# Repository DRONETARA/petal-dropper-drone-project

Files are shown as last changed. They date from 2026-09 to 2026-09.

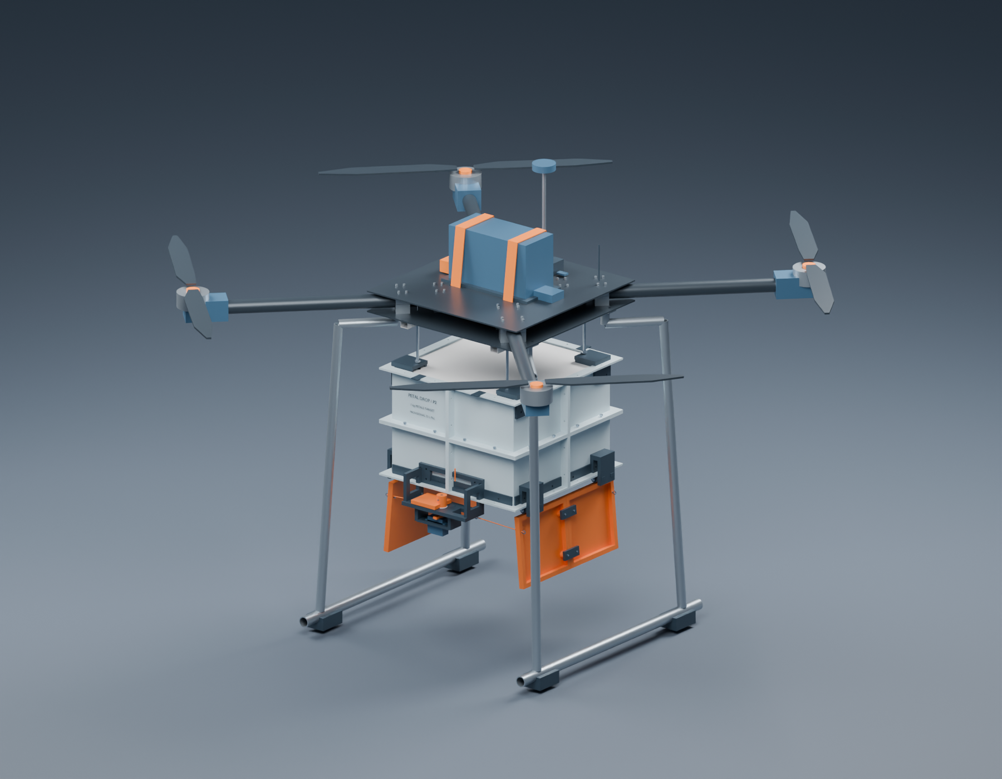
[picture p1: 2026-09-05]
deliverables/P2_selected_build_view_copy/Assembly_open.png

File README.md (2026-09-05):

# Petal Dropper Drone Project

This repository contains the complete Blender design package for Dronetara's flower-petal dropper drone. The current deliverable is P2: a selected-aircraft digital prototype with a 1 kg flower-petal target.

Start here:

- `deliverables/P2_selected_build/PetalDrop_1kg_Assembly.blend` is the editable P2 assembly in millimetres.
- `deliverables/P2_selected_build/STL_mm/` contains 46 individual printable attachment parts. Import at 100% in millimetres.
- `deliverables/P2_selected_build/README.md` is the build and assembly guide.
- `deliverables/P2_selected_build/Selected_components_BOM.csv`, `Electrical_and_Setup.md`, `Mass_and_Performance.md`, and `Fabrication/` contain the component selection, wiring approach, sizing, DXFs, and machining references.
- `deliverables/flap_opening_animation/PetalDrop_Flaps_Opening.mp4` is an 8.13-second close-up of the keeper release and flap opening. `PetalDrop_Flap_Opening_Review.blend` is the editable animation review scene; press Space in Blender to play it.

P2 selects a 1,300 mm Quad X with four Hobbywing X6 Plus G2 propulsion units, a Tattu 12S 22 Ah battery, Pixhawk 6X, PM08-CAN power module, M10 GPS, ELRS receiver, and two Hitec D954SW release servos. The package also retains the original starter assembly and P1 attachment prototype under `deliverables/`.

The design is a digital prototype, not a flight-ready aircraft. It targets 1 kg of petals, and its planning mass is about 20.3 kg including the target petals and contingency. Actual petal capacity, printed-part strength, release reliability, electronics, propulsion, landing structure, and flight performance are untested. The P2 qualification worksheet records the physical tests still required.

`packages/Dronetara_P2_Selected_Build.zip` is the standalone P2 handoff archive. `source/` retains the useful generation scripts, while P2's portable regeneration sources are also inside `deliverables/P2_selected_build/Source/`.

## Repository layout

| Path | Contents |
| --- | --- |
| `deliverables/Dronetara_Starter.blend` | Original editable starter drone |
| `deliverables/P1_attachment_prototype/` | Earlier P1 attachment, STL set, checks, and preview renders |
| `deliverables/P2_selected_build/` | Current selected-aircraft build package and 46-printable-part STL set |
| `deliverables/P2_selected_build_view_copy/` | Preserved alternate P2 Blender view copy; use the P2 build folder as canonical documentation |
| `deliverables/flap_opening_animation/` | Opening animation MP4, review Blender file, source frames, and verification notes |
| `packages/` | Portable P2 ZIP handoff |
| `source/` | Historical generation scripts used to create the project assets |

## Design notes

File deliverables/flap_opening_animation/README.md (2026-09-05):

# PetalDrop flap-opening animation

`PetalDrop_Flaps_Opening.mp4`: 8.13-second H.264 video, 800 x800, with a final open hold. Shows the existing keeper-release and two-door opening sequence. No flower particles or physics simulation are claimed.

`PetalDrop_Flap_Opening_Review.blend`: separate editable close-up presentation. Camera view, timeline1–105 at15fps; press Space in the viewport to play. The original P2 assembly and its full manual-reset timeline remain unchanged. Landing references are hidden in this review for visibility.

Verified poses: closed at1, keepers90°/doorsclosed at50, keepers90°/doors±95° at90.53 rendered source images, encoded at7.5 source frames/second into a30fps playback file. Full video decode succeeded and an extracted final frame was visually checked. Original P2 saved-file checksum is unchanged. Existing opening playback was also observed in the active Blender UI; the user's actively changing view was not replaced.

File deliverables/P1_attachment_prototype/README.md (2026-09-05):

# PetalDrop P1 — 1 kg petal-target bench prototype

**The target is at least 1 kg of flower petals alone.** The previous 200 g request is superseded. This package contains an editable drone-and-attachment assembly, 46 separate printable attachment parts, and an illustrated release/reset sequence. It is an untested mechanical prototype, not a demonstrated 1 kg-capable aircraft or a physically validated release system.

The original `Dronetara_Starter.blend` and its preview remain unchanged in the parent output folder. The new assembly uses the original visual drone enlarged **2.5 times in physical dimensions**, with an illustrative extended landing stand. That enlargement does not establish motor thrust, frame strength, endurance, or payload rating.

## Files and operation

- `PetalDrop_1kg_Assembly.blend`: editable assembly. One Blender unit represents one millimetre (`scale_length = 0.001`). Printable components are grouped in collections 10–14; purchased hardware and reference parts are separate.
- `STL_mm/`: 46 individual attachment components, one copy of each filename. STL has no intrinsic unit field: import as **millimetres, at 100% scale**. These files do not contain the decorative drone or landing stand.
- `parts_manifest.csv` / `.json`: each part's dimensions, quantity, nominal solid PETG mass and notes.
- `Assembly_closed.png`, `Assembly_open.png`: complete aircraft/reference-attachment views.
- `Mechanism_open.png`: better-lit underside detail; reference landing legs are hidden for this image only.
- `verification.json`: Blender topology, nominal wall/volume data and timeline collision sampling.
- `final_checks.json`: independent validation of the delivered STL binaries and a one-degree mechanism sweep, including reference landing legs.
- `limit_cords.json`: provisional door-stop cord lengths and assumptions.
- `hardware_BOM.csv`: purchased/fabricated hardware, separate from the print list.

Timeline markers describe the mechanism, rather than a physics simulation:

| Frames | State |
|---|---|
| 1 | Doors closed; keepers overlap the door ribs; removable transport pins installed |
| 20 | Both transport pins removed; operator has armed the mechanism |
| 20–50 | Two servos rotate the mechanical keepers through 90 degrees |
| 50–90 | Both doors swing down under gravity to the provisional 95-degree cord limit |
| 90–105 | Discharge opening exposed |
| 105–125 | **Manual** lifting of the empty doors, represented by keyframes |
| 125–155 | Servos return the keepers under the raised doors |
| 180 | Transport pins reinstalled |

This design intentionally uses gravity opening and manual reset. The servos do not lift 1 kg of petals or raise the doors. Support both empty doors by hand during reset, then close the keepers and insert the transport pins. Never command keeper closure into partly raised doors.

## Geometry and capacity assumptions

| Item | Provisional value |
|---|---:|
| Internal hopper plan | 320 × 320 mm |
| Interior bottom datum / top | Z354 / Z590 mm |
| Nominal gross enclosed volume | 24.166 L |
| Fill line | Z570 mm; 20 mm below the top |
| Geometric volume below fill line | 22.118 L, before displacement by hardware/cover |
| Minimum bulk density for 1 kg in that volume | 45.21 kg/m³; actual required density is slightly higher with displaced volume |
| Clear throat between support lips | 292 × 292 mm |
| Main hopper walls / bolt flanges | 2.4 / 4 mm |
| Door skins / ribs below skins | 2.4 / 9.6 mm |
| Module seam gap | 0.4 mm, sealed externally after assembly |
| Closed door skin to throat lip | 2 mm nominal vertical gap |
| Closed keeper to door rib | 0.5 mm nominal gap; doors settle onto keepers under load |
| Hinge pin / printed bore | 5.0 / 5.4 mm |
| Door knuckle to clevis | 2 mm nominal axial clearance at each end |
| Common M4 clearance holes | 4.4 mm |
| Provisional printer envelope | 220 × 220 × 220 mm |

The smooth interior and broad bottom opening reduce small-throat bridging risk, but wet petals, tangled petals and propwash can still prevent clean release. The cover is a **nonprinted fabric/net retention cover**, not a printed lid. Secure it around the rim and reinforce its four suspension-stud openings. The cover and fasteners displace some of the geometric volume.

### Measure the petals before claiming capacity

1. Weigh representative petals using the same variety, moisture and handling expected in use.
2. Fill a known-volume container loosely, without compressing the petals to make them fit. Repeat several times, including the loosest expected batch.
3. Compute bulk density as `mass_kg / volume_m³`, or required volume as `1 kg / measured density`.
4. Then test a full 1 kg batch in the assembled hopper below the fill line, with the cover installed. Record residual petals after release.

If the loosest batch needs more than the usable volume, this hopper does **not** meet the 1 kg requirement for that batch. Increase hopper volume or change the loading method and recheck the mechanism, mass, printer splits and clearances. No petal density was invented or measured during this design task.

## Mechanical load path and restraint

Petals rest on the ribbed doors. Door load is shared by the four steel-pin hinges and two wide keeper dogs. Each keeper overlaps the inner edges of **both** doors. Its axial load passes through a thrust washer into the printed carrier shelf, then through M4 fasteners into the hopper. The servo supplies rotation through a separate 6 mm spindle; its output bearing is not the intended vertical load support.

Hopper forces pass through the bolted corner shells to four suspension brackets, four M6 studs and two aluminium square-tube rails. Four rail clamps show a provisional connection to the visual airframe. Use through-bolts, washers and locking nuts rather than relying on printed threads.

Four adjustable, **nonprinted** 2 mm limit cords connect the keeper-carrier shelves to eye bolts on the door end ribs. Their geometry provides a nominal 95-degree opening stop. See `limit_cords.json` for eye-centre length; add the actual eye/loop/knot allowance and adjust on the physical assembly. Cord shape in Blender is illustrative. Verify routing, abrasion, shock load, knot security and angle before operating. The eye bolts and cord anchors are not strength-certified.

The small torsion-spring shapes are explicitly **hardware placeholders**. A spring, its end anchors and preload have not been selected or engineered. Do not rely on these shapes for automatic return or a power-loss fail-safe. The removable 3 mm transport pins are positive mechanical restraints when installed; remove both before servo actuation. Determine the required in-service power-loss behaviour before any aircraft integration.

## Mass, lift and actuator requirements

The mesh-volume estimate is approximately **3.73 kg for fully solid PETG**, using an assumed density of 1.27 g/cm³. This is not a slicer result or weighed mass. Infill may reduce some thick-part mass, while supports, hardware and finishing change the actual totals. Thin walls cannot be treated as empty infill volumes.

| Load item | Current status |
|---|---|
| Petals | Required target: **at least 1.000 kg** |
| Printed attachment | Approximately 3.73 kg if solid PETG; see manifest for exact current estimate |
| Rails, studs, fasteners, actuators, cover, cords, wiring | Provisional planning allowance **1.0–1.4 kg**; choose and weigh actual hardware |
| Added load carried by aircraft | Approximately **5.7–6.1 kg** under the solid-print assumption, excluding any new landing gear |
| Actual drone empty mass, lift margin and endurance | Unknown |

The attachment is therefore a substantial bench prototype, not a demonstrated lightweight flight payload. Slicer estimates and a weighed build are required before matching it to an airframe. The visual drone's propellers, motors and enlarged geometry supply no evidence of lift capacity.

For an **illustrative, unvalidated 3 g load case**, 5.7–6.1 kg creates about 168–180 N total vertical force, or 42–45 N per suspension point if perfectly shared. Real loads need not share evenly. This calculation is a sizing input only: no material coupon testing, stress analysis, fatigue assessment, pull-out test or structural proof test was performed.

Each servo model is a placeholder, not a verified purchasable actuator. The current interface assumes:

- Body envelope: 40.5 × 20.5 × 40 mm, with shaft axis offset 10 mm from body centre.
- Ear-hole pattern: 49.5 × 10 mm, using 3.4 mm printed clearance holes.
- Purchased horn: four M2.5 attachment screws on a **provisional 17 mm pitch circle**.
- Separate 6 mm steel spindle with two M3 cross-bolt connections. Confirm actual shaft machining, fit, fastener strength and access.
- At least 90 degrees of usable commanded travel, with calibrated closed/open limits.

A conservative starting selection calculation is `T ≈ friction coefficient × supported force × contact radius`. Assuming 0.4 friction, about 1.7 kg of doors plus petals temporarily loading one keeper, and a 60 mm effective radius gives roughly **0.4 N·m**. A factor of three gives **1.2 N·m of verified usable torque**, before spring, dirt or jam allowances. This is not a stall-torque endorsement or a measured requirement. Select the actuator using its real voltage, duty and torque data, then rework the provisional horn adapter and carrier if needed.

Power the actuators from a correctly rated supply/BEC; establish stall/current demand and signal compatibility from the selected hardware. Do not assume an autopilot's signal header can power two high-torque servos. No autopilot wiring, software or failsafe configuration is supplied because the controller is unknown.

## Printing and assembly

All 46 files fit within the provisional 220 mm cube. Each STL is translated to the build plane and oriented along a bounding-box axis; this is a packaging orientation, **not a guarantee of support-free printing or optimal layer strength**. Confirm orientation in the slicer.

Suggested starting process: calibrated 0.4 mm nozzle and 0.2 mm layers. The 2.4 mm skins are nominally six 0.4 mm extrusion widths, but actual slicer line width matters. Print a hinge/clearance sample before the full set. Use a suitable tested material profile and orient structural brackets so primary loads do not simply peel apart layer interfaces. No generic infill percentage establishes strength.

1. Assemble the eight hopper corner modules with M4 screws, wide washers and locknuts. Keep the 0.4 mm seam gaps consistent and seal them externally. Do not rely on adhesive alone.
2. Add the eight throat rails, four hinge clevises and four upper suspension brackets using their matching through-holes.
3. Join each two-tile door using its two underside splice plates. Fit steel hinge pins, thrust washers and positive pin retention. Check free rotation with the servos/cords disconnected.
4. Assemble each keeper carrier, thrust washer, spindle, keeper and **hardware-matched** horn adapter. Install the selected actuator and verify its mounting and output axis before tightening.
5. Fit the four M4 limit-cord eye anchors on carriers and four on doors. Adjust the four cords evenly while physically supporting the open doors. Check that slack cords stay clear of latches, shafts and the release opening.
6. Fit the M6 suspension studs, rails and removable rail clamps. The airframe interface must be adapted to the actual frame, not drilled from the decorative model by assumption.
7. Secure the fabric cover, wiring and any tethering so nothing can enter the propellers or catch a door.

Fastener lengths in the BOM are provisional. Measure the assembled stack, allow full nut engagement, retain moving pins, and check that projecting threads do not obstruct petals or moving parts.

## Verification and physical tests still required

The final reports distinguish Blender topology checks from independent **STL-binary** checks. Tiny boolean slivers were cleaned at 0.001 mm tolerance, and mirrored normals were corrected. Confirm the latest `final_checks.json`: all delivered files should have zero boundary/nonmanifold edges, zero degenerate triangles and positive signed volume.

The mechanism was also swept at one-degree increments through keeper release and door opening, checking printed parts against fixed print geometry and the illustrative landing legs. This is sampled surface-intersection checking, not a continuous collision proof or a deformation/contact simulation. Metal pins, washers, springs, servo internals, wiring, cables under load and real petals require physical checks. Nominal wall/skin dimensions are design inputs, not a complete minimum-wall scan of every bolt ligament.

Before evaluating a flight installation:

- **Dimensional fit:** gauge every pin, eye, bolt, actuator and rail fit; check washer/nut access and full travel by hand.
- **Loaded retention:** support the assembly in a bench fixture with propellers removed. Load an actual 1 kg batch, hold it closed, inspect deflection and verify that both keepers and all pins remain secure. Establish proof loads with an engineer from the intended acceleration and material data.
- **Release reliability:** measure commanded-to-release time, current peaks, servo temperature, residual mass and any asymmetric opening. Repeat with dry and damp petals, partial/full fills and expected gentle motion. A useful initial screening is 20 successful bench releases; it is not a reliability qualification.
- **Reset/transport:** test manual reset, the two removable pins and cord routing after every cycle. Define and test loss-of-power behaviour.
- **Actual aircraft:** obtain frame mounting dimensions, permitted takeoff mass, motor/propeller/battery data, thrust margin, payload CG limits, controller/servo interface and real ground clearance. Include the entire attachment, hardware and modified landing gear in the load budget.

### Design references

Printing orientation and fit allowances must be adapted to the process; see [Prusa: Modeling with 3D printing in mind](https://help.prusa3d.com/article/modeling-with-3d-printing-in-mind_164135).

Servo supply sizing must account for current demand rather than signal compatibility alone; see [Pololu: Electrical characteristics of servos](https://www.pololu.com/blog/16/electrical-characteristics-of-servos-and-introduction-to-the-servo-control-interface).

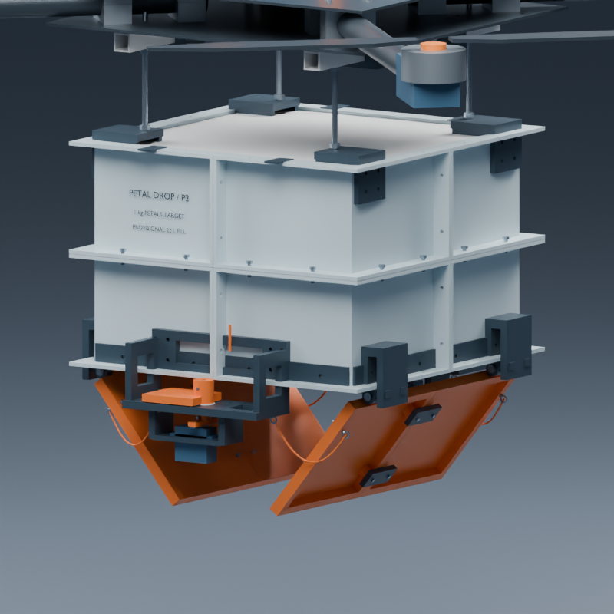
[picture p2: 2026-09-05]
deliverables/flap_opening_animation/frames/frame_0071.png

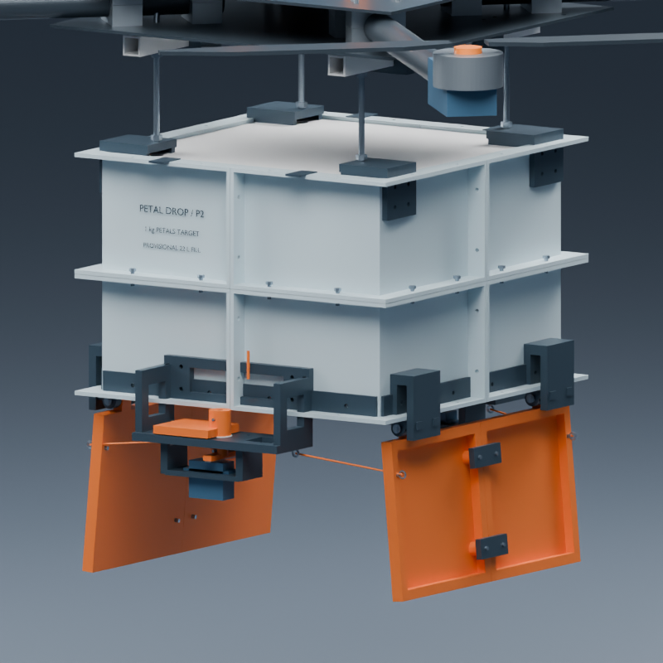
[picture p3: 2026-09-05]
deliverables/flap_opening_animation/frames/frame_0093.png

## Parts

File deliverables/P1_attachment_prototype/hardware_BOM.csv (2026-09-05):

Item | Quantity | Provisional size or interface | Notes
Hopper module joining bolts | 32 | M4 x 16 with washers and locknuts | 16 vertical seam and 16 horizontal seam bolts
Throat rail bolts | 16 | M4 x 14 with washers and locknuts | Check stacked wall and rail thickness
Hinge clevis mounting bolts | 16 | M4 x 20 with washers and locknuts | Verify engagement and no projecting petal snags
Keeper carrier mounting bolts | 16 | M4 x 20 with washers and locknuts | Four bolt holes on each half of each carrier
Suspension bracket bolts | 16 | M4 x 18 with wide washers and locknuts | Load path into thin hopper wall requires testing
Door splice bolts | 8 | M4 x 22 with washers and locknuts | Two bolts per splice plate
Rail clamp bolts | 16 | M4 x 40 with washers and locknuts | Four bolts per split clamp; actual frame interface unknown
Door-limit eye bolts | 8 | M4 with washers and locknuts | Four carrier anchors and four door anchors; select stem length from actual stack
Door-limit cords | 4 | 2 mm nominal adjustable cord | Provisional 100 N WLL target each; eye-centre lengths in limit_cords.json; verify knots and shock load
Hinge pins | 4 | 5 mm stainless steel x 48 mm | Add washers and positive end retention; not printed pins
Hinge thrust washers | 8 | 5 mm ID | Allow for actual washer thickness when fitting
Keeper spindles | 2 | 6 mm steel x 44 mm | Two M3 cross connections; machining and strength need review
Spindle cross bolts | 4 | M3 x 26 with locking nuts | Match shaft and adapter hole alignment
Keeper thrust washers | 2 | 6.6 mm ID x 24 mm OD x 1 mm | Payload axial force bears on carrier shelf
Transport arming pins | 2 | 3 mm x 28 mm with retention loop | Remove both before commanded release
Servos | 2 | UNSELECTED; provisional 40.5 x 20.5 x 40 mm | Verify usable torque not stall rating; voltage duty current horn and hole pattern
Servo mounting screws | 8 | M3 with washers and locking nuts | Provisional 49.5 x 10 mm mounting pattern
Purchased servo horns | 2 | UNSELECTED; provisional 17 mm four-hole PCD | Printed adapter is not a verified servo spline
Horn adapter screws | 8 | M2.5 | Actual horn determines length and pattern
Return springs | 2 | UNSELECTED; shown schematically only | End anchors and preload not engineered; not a verified failsafe
Suspension studs | 4 | M6 x 136 mm | Use actual frame dimensions before cutting
Suspension nuts | 12 | M6 locking nuts plus wide washers | Verify clearance and secure engagement
Mount rails | 2 | Aluminium square tube 20 x 20 x 2 mm x 350 mm | Drill M6 stud holes at +/-130 mm; actual frame interface unknown
Retention cover | 1 | Light fabric or suitable net about 320 x 320 mm | Reinforce four stud cutouts and secure all edges; validate propwash
Cover straps | 4 | Nonprinted straps | Keep away from propellers
Power supply and wiring | 1 | UNSELECTED BEC wiring connector set | Size for selected actuators and actual controller interface
Illustrative landing stand | 0 | Not included in printable attachment BOM | New landing gear must be engineered and counted in actual aircraft mass

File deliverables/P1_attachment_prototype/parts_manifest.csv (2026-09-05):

part | STL file | quantity | X mm | Y mm | Z mm | solid PETG grams | nonmanifold edges | components | print notes
Hopper_lower_-1_-1 | Hopper_lower_m1_m1.stl | 1 | 181.8 | 181.8 | 119.8 | 206.9 | 0 | 1 | 2.4 mm walls; 4 mm outside bolt flanges; 0.4 mm module gaps. M4 through-bolts, washers, locknuts. Seal joints externally with tape. Print with flange supports. Mesh merged at 0.001 mm tolerance; outward STL normals verified. Mesh merged at 0.001 mm tolerance; outward STL normals verified.
Hopper_lower_-1_+1 | Hopper_lower_m1_p1.stl | 1 | 181.8 | 181.8 | 119.8 | 206.9 | 0 | 1 | 2.4 mm walls; 4 mm outside bolt flanges; 0.4 mm module gaps. M4 through-bolts, washers, locknuts. Seal joints externally with tape. Print with flange supports. Mesh merged at 0.001 mm tolerance; outward STL normals verified. Mesh merged at 0.001 mm tolerance; outward STL normals verified.
Hopper_lower_+1_-1 | Hopper_lower_p1_m1.stl | 1 | 181.8 | 181.8 | 119.8 | 206.9 | 0 | 1 | 2.4 mm walls; 4 mm outside bolt flanges; 0.4 mm module gaps. M4 through-bolts, washers, locknuts. Seal joints externally with tape. Print with flange supports. Mesh merged at 0.001 mm tolerance; outward STL normals verified. Mesh merged at 0.001 mm tolerance; outward STL normals verified.
Hopper_lower_+1_+1 | Hopper_lower_p1_p1.stl | 1 | 181.8 | 181.8 | 119.8 | 206.9 | 0 | 1 | 2.4 mm walls; 4 mm outside bolt flanges; 0.4 mm module gaps. M4 through-bolts, washers, locknuts. Seal joints externally with tape. Print with flange supports. Mesh merged at 0.001 mm tolerance; outward STL normals verified. Mesh merged at 0.001 mm tolerance; outward STL normals verified.
Hopper_upper_-1_-1 | Hopper_upper_m1_m1.stl | 1 | 181.8 | 181.8 | 119.8 | 207.2 | 0 | 1 | 2.4 mm walls; 4 mm outside bolt flanges; 0.4 mm module gaps. M4 through-bolts, washers, locknuts. Seal joints externally with tape. Print with flange supports. Mesh merged at 0.001 mm tolerance; outward STL normals verified. Mesh merged at 0.001 mm tolerance; outward STL normals verified.
Hopper_upper_-1_+1 | Hopper_upper_m1_p1.stl | 1 | 181.8 | 181.8 | 119.8 | 207.2 | 0 | 1 | 2.4 mm walls; 4 mm outside bolt flanges; 0.4 mm module gaps. M4 through-bolts, washers, locknuts. Seal joints externally with tape. Print with flange supports. Mesh merged at 0.001 mm tolerance; outward STL normals verified. Mesh merged at 0.001 mm tolerance; outward STL normals verified.
Hopper_upper_+1_-1 | Hopper_upper_p1_m1.stl | 1 | 181.8 | 181.8 | 119.8 | 207.2 | 0 | 1 | 2.4 mm walls; 4 mm outside bolt flanges; 0.4 mm module gaps. M4 through-bolts, washers, locknuts. Seal joints externally with tape. Print with flange supports. Mesh merged at 0.001 mm tolerance; outward STL normals verified. Mesh merged at 0.001 mm tolerance; outward STL normals verified.
Hopper_upper_+1_+1 | Hopper_upper_p1_p1.stl | 1 | 181.8 | 181.8 | 119.8 | 207.2 | 0 | 1 | 2.4 mm walls; 4 mm outside bolt flanges; 0.4 mm module gaps. M4 through-bolts, washers, locknuts. Seal joints externally with tape. Print with flange supports. Mesh merged at 0.001 mm tolerance; outward STL normals verified. Mesh merged at 0.001 mm tolerance; outward STL normals verified.
Throat_rail_X_-1_-1 | Throat_rail_X_m1_m1.stl | 1 | 159.6 | 24.0 | 19.4 | 27.8 | 0 | 1 | Inward 12 mm support lip; 2 mm vertical clearance over shut doors. M4 attachment. Clear aperture 292 x 292 mm. Mesh merged at 0.001 mm tolerance; outward STL normals verified. Mesh merged at 0.001 mm tolerance; outward STL normals verified.
Throat_rail_X_-1_+1 | Throat_rail_X_m1_p1.stl | 1 | 159.6 | 24.0 | 19.4 | 27.8 | 0 | 1 | Inward 12 mm support lip; 2 mm vertical clearance over shut doors. M4 attachment. Clear aperture 292 x 292 mm. Mesh merged at 0.001 mm tolerance; outward STL normals verified. Mesh merged at 0.001 mm tolerance; outward STL normals verified.
Throat_rail_X_+1_-1 | Throat_rail_X_p1_m1.stl | 1 | 159.6 | 24.0 | 19.4 | 27.8 | 0 | 1 | Inward 12 mm support lip; 2 mm vertical clearance over shut doors. M4 attachment. Clear aperture 292 x 292 mm. Mesh merged at 0.001 mm tolerance; outward STL normals verified. Mesh merged at 0.001 mm tolerance; outward STL normals verified.
Throat_rail_X_+1_+1 | Throat_rail_X_p1_p1.stl | 1 | 159.6 | 24.0 | 19.4 | 27.8 | 0 | 1 | Inward 12 mm support lip; 2 mm vertical clearance over shut doors. M4 attachment. Clear aperture 292 x 292 mm. Mesh merged at 0.001 mm tolerance; outward STL normals verified. Mesh merged at 0.001 mm tolerance; outward STL normals verified.
Throat_rail_Y_-1_-1 | Throat_rail_Y_m1_m1.stl | 1 | 24.0 | 159.6 | 19.4 | 26.6 | 0 | 1 | Inward 12 mm support lip; 2 mm vertical clearance over shut doors. M4 attachment. Clear aperture 292 x 292 mm. Mesh merged at 0.001 mm tolerance; outward STL normals verified. Mesh merged at 0.001 mm tolerance; outward STL normals verified.
Throat_rail_Y_-1_+1 | Throat_rail_Y_m1_p1.stl | 1 | 24.0 | 159.6 | 19.4 | 26.6 | 0 | 1 | Inward 12 mm support lip; 2 mm vertical clearance over shut doors. M4 attachment. Clear aperture 292 x 292 mm. Mesh merged at 0.001 mm tolerance; outward STL normals verified. Mesh merged at 0.001 mm tolerance; outward STL normals verified.
Throat_rail_Y_+1_-1 | Throat_rail_Y_p1_m1.stl | 1 | 24.0 | 159.6 | 19.4 | 26.6 | 0 | 1 | Inward 12 mm support lip; 2 mm vertical clearance over shut doors. M4 attachment. Clear aperture 292 x 292 mm. Mesh merged at 0.001 mm tolerance; outward STL normals verified. Mesh merged at 0.001 mm tolerance; outward STL normals verified.
Throat_rail_Y_+1_+1 | Throat_rail_Y_p1_p1.stl | 1 | 24.0 | 159.6 | 19.4 | 26.6 | 0 | 1 | Inward 12 mm support lip; 2 mm vertical clearance over shut doors. M4 attachment. Clear aperture 292 x 292 mm. Mesh merged at 0.001 mm tolerance; outward STL normals verified. Mesh merged at 0.001 mm tolerance; outward STL normals verified.
Door_tile_-1_-1 | Door_tile_m1_m1.stl | 1 | 176.5 | 159.3 | 16.0 | 156.0 | 0 | 1 | 2.4 mm skin; 9.6 mm ribs; 5.4 mm pin bore. Print flat with ribs upward. M4 splice plates underneath. Mesh merged at 0.001 mm tolerance; outward STL normals verified. Mesh merged at 0.001 mm tolerance; outward STL normals verified.
Hinge_clevis_-1_-1 | Hinge_clevis_m1_m1.stl | 1 | 48.0 | 64.0 | 30.0 | 63.2 | 0 | 1 | M4 bolts to hopper wall; 5 mm stainless pin, washers and split pins. 2 mm axial running clearance per side. Mesh merged at 0.001 mm tolerance; outward STL normals verified. Mesh merged at 0.001 mm tolerance; outward STL normals verified.
Door_tile_-1_+1 | Door_tile_m1_p1.stl | 1 | 176.5 | 159.3 | 16.0 | 156.0 | 0 | 1 | 2.4 mm skin; 9.6 mm ribs; 5.4 mm pin bore. Print flat with ribs upward. M4 splice plates underneath. Mesh merged at 0.001 mm tolerance; outward STL normals verified. Mesh merged at 0.001 mm tolerance; outward STL normals verified.
Hinge_clevis_-1_+1 | Hinge_clevis_m1_p1.stl | 1 | 48.0 | 64.0 | 30.0 | 63.2 | 0 | 1 | M4 bolts to hopper wall; 5 mm stainless pin, washers and split pins. 2 mm axial running clearance per side. Mesh merged at 0.001 mm tolerance; outward STL normals verified. Mesh merged at 0.001 mm tolerance; outward STL normals verified.
Door_splice_-1_35 | Door_splice_m1_35.stl | 1 | 20.0 | 48.0 | 6.0 | 7.1 | 0 | 1 | M4 x 22 through-bolts; underside of tile joint. Mesh merged at 0.001 mm tolerance; outward STL normals verified. Mesh merged at 0.001 mm tolerance; outward STL normals verified.
Door_splice_-1_125 | Door_splice_m1_125.stl | 1 | 20.0 | 48.0 | 6.0 | 7.1 | 0 | 1 | M4 x 22 through-bolts; underside of tile joint. Mesh merged at 0.001 mm tolerance; outward STL normals verified. Mesh merged at 0.001 mm tolerance; outward STL normals verified.
Door_tile_+1_-1 | Door_tile_p1_m1.stl | 1 | 176.5 | 159.3 | 16.0 | 156.0 | 0 | 1 | 2.4 mm skin; 9.6 mm ribs; 5.4 mm pin bore. Print flat with ribs upward. M4 splice plates underneath. Mesh merged at 0.001 mm tolerance; outward STL normals verified. Mesh merged at 0.001 mm tolerance; outward STL normals verified.
Hinge_clevis_+1_-1 | Hinge_clevis_p1_m1.stl | 1 | 48.0 | 64.0 | 30.0 | 63.2 | 0 | 1 | M4 bolts to hopper wall; 5 mm stainless pin, washers and split pins. 2 mm axial running clearance per side. Mesh merged at 0.001 mm tolerance; outward STL normals verified. Mesh merged at 0.001 mm tolerance; outward STL normals verified.
Door_tile_+1_+1 | Door_tile_p1_p1.stl | 1 | 176.5 | 159.3 | 16.0 | 156.0 | 0 | 1 | 2.4 mm skin; 9.6 mm ribs; 5.4 mm pin bore. Print flat with ribs upward. M4 splice plates underneath. Mesh merged at 0.001 mm tolerance; outward STL normals verified. Mesh merged at 0.001 mm tolerance; outward STL normals verified.
Hinge_clevis_+1_+1 | Hinge_clevis_p1_p1.stl | 1 | 48.0 | 64.0 | 30.0 | 63.2 | 0 | 1 | M4 bolts to hopper wall; 5 mm stainless pin, washers and split pins. 2 mm axial running clearance per side. Mesh merged at 0.001 mm tolerance; outward STL normals verified. Mesh merged at 0.001 mm tolerance; outward STL normals verified.
Door_splice_+1_35 | Door_splice_p1_35.stl | 1 | 20.0 | 48.0 | 6.0 | 7.1 | 0 | 1 | M4 x 22 through-bolts; underside of tile joint. Mesh merged at 0.001 mm tolerance; outward STL normals verified. Mesh merged at 0.001 mm tolerance; outward STL normals verified.
Door_splice_+1_125 | Door_splice_p1_125.stl | 1 | 20.0 | 48.0 | 6.0 | 7.1 | 0 | 1 | M4 x 22 through-bolts; underside of tile joint. Mesh merged at 0.001 mm tolerance; outward STL normals verified. Mesh merged at 0.001 mm tolerance; outward STL normals verified.
Keeper_dog_-1 | Keeper_dog_m1.stl | 1 | 56.0 | 71.0 | 25.0 | 44.3 | 0 | 1 | Positive overlap under BOTH leaves; 90 degree release. 6 mm spindle; M3 cross-bolt. Removable 3 mm arming pin. Servo must return closed before manual reset. Mesh merged at 0.001 mm tolerance; outward STL normals verified. Mesh merged at 0.001 mm tolerance; outward STL normals verified.
Servo_keeper_carrier_-1 | Servo_keeper_carrier_m1.stl | 1 | 97.0 | 170.0 | 65.6 | 207.0 | 0 | 1 | Shelf carries axial petal load via washer, not servo output bearing. Actuator envelope/49.5 x 10 hole pattern provisional; verify against purchased hardware. Mesh merged at 0.001 mm tolerance; outward STL normals verified. Mesh merged at 0.001 mm tolerance; outward STL normals verified.
Horn_adapter_PROVISIONAL_-1 | Horn_adapter_PROVISIONAL_m1.stl | 1 | 28.0 | 28.0 | 12.5 | 5.0 | 0 | 1 | Not a verified servo spline. Bolts to purchased horn: assumed four M2.5 holes on 17 mm PCD. Rework this adapter after selecting hardware. Mesh merged at 0.001 mm tolerance; outward STL normals verified. Mesh merged at 0.001 mm tolerance; outward STL normals verified.
Keeper_dog_+1 | Keeper_dog_p1.stl | 1 | 56.0 | 71.0 | 25.0 | 44.3 | 0 | 1 | Positive overlap under BOTH leaves; 90 degree release. 6 mm spindle; M3 cross-bolt. Removable 3 mm arming pin. Servo must return closed before manual reset. Mesh merged at 0.001 mm tolerance; outward STL normals verified. Mesh merged at 0.001 mm tolerance; outward STL normals verified.
Servo_keeper_carrier_+1 | Servo_keeper_carrier_p1.stl | 1 | 97.0 | 170.0 | 65.6 | 207.0 | 0 | 1 | Shelf carries axial petal load via washer, not servo output bearing. Actuator envelope/49.5 x 10 hole pattern provisional; verify against purchased hardware. Mesh merged at 0.001 mm tolerance; outward STL normals verified. Mesh merged at 0.001 mm tolerance; outward STL normals verified.
Horn_adapter_PROVISIONAL_+1 | Horn_adapter_PROVISIONAL_p1.stl | 1 | 28.0 | 28.0 | 12.5 | 5.0 | 0 | 1 | Not a verified servo spline. Bolts to purchased horn: assumed four M2.5 holes on 17 mm PCD. Rework this adapter after selecting hardware. Mesh merged at 0.001 mm tolerance; outward STL normals verified. Mesh merged at 0.001 mm tolerance; outward STL normals verified.
Suspension_bracket_-1_-1 | Suspension_bracket_m1_m1.stl | 1 | 56.4 | 52.0 | 52.0 | 56.7 | 0 | 1 | M6 removable suspension stud; four M4 wall bolts and large washers. Structural capacity untested. Mesh merged at 0.001 mm tolerance; outward STL normals verified. Mesh merged at 0.001 mm tolerance; outward STL normals verified.
Suspension_bracket_-1_+1 | Suspension_bracket_m1_p1.stl | 1 | 56.4 | 52.0 | 52.0 | 56.7 | 0 | 1 | M6 removable suspension stud; four M4 wall bolts and large washers. Structural capacity untested. Mesh merged at 0.001 mm tolerance; outward STL normals verified. Mesh merged at 0.001 mm tolerance; outward STL normals verified.
Suspension_bracket_+1_-1 | Suspension_bracket_p1_m1.stl | 1 | 56.4 | 52.0 | 52.0 | 56.7 | 0 | 1 | M6 removable suspension stud; four M4 wall bolts and large washers. Structural capacity untested. Mesh merged at 0.001 mm tolerance; outward STL normals verified. Mesh merged at 0.001 mm tolerance; outward STL normals verified.
Suspension_bracket_+1_+1 | Suspension_bracket_p1_p1.stl | 1 | 56.4 | 52.0 | 52.0 | 56.7 | 0 | 1 | M6 removable suspension stud; four M4 wall bolts and large washers. Structural capacity untested. Mesh merged at 0.001 mm tolerance; outward STL normals verified. Mesh merged at 0.001 mm tolerance; outward STL normals verified.
Rail_clamp_upper_-1_-1 | Rail_clamp_upper_m1_m1.stl | 1 | 50.0 | 36.0 | 5.0 | 11.0 | 0 | 1 | Top plane Z715. Four M4 bolts on 38 x 20 mm pattern. Actual drone interface UNVERIFIED. Mesh merged at 0.001 mm tolerance; outward STL normals verified. Mesh merged at 0.001 mm tolerance; outward STL normals verified.
Rail_clamp_lower_-1_-1 | Rail_clamp_lower_m1_m1.stl | 1 | 50.0 | 36.0 | 28.0 | 40.6 | 0 | 1 | 20.8 mm square tube clearance. Use M4 through-bolts; no printed threads. Fit coupon first. Mesh merged at 0.001 mm tolerance; outward STL normals verified. Mesh merged at 0.001 mm tolerance; outward STL normals verified.
Rail_clamp_upper_-1_+1 | Rail_clamp_upper_m1_p1.stl | 1 | 50.0 | 36.0 | 5.0 | 11.0 | 0 | 1 | Top plane Z715. Four M4 bolts on 38 x 20 mm pattern. Actual drone interface UNVERIFIED. Mesh merged at 0.001 mm tolerance; outward STL normals verified. Mesh merged at 0.001 mm tolerance; outward STL normals verified.
Rail_clamp_lower_-1_+1 | Rail_clamp_lower_m1_p1.stl | 1 | 50.0 | 36.0 | 28.0 | 40.6 | 0 | 1 | 20.8 mm square tube clearance. Use M4 through-bolts; no printed threads. Fit coupon first. Mesh merged at 0.001 mm tolerance; outward STL normals verified. Mesh merged at 0.001 mm tolerance; outward STL normals verified.
Rail_clamp_upper_+1_-1 | Rail_clamp_upper_p1_m1.stl | 1 | 50.0 | 36.0 | 5.0 | 11.0 | 0 | 1 | Top plane Z715. Four M4 bolts on 38 x 20 mm pattern. Actual drone interface UNVERIFIED. Mesh merged at 0.001 mm tolerance; outward STL normals verified. Mesh merged at 0.001 mm tolerance; outward STL normals verified.
Rail_clamp_lower_+1_-1 | Rail_clamp_lower_p1_m1.stl | 1 | 50.0 | 36.0 | 28.0 | 40.6 | 0 | 1 | 20.8 mm square tube clearance. Use M4 through-bolts; no printed threads. Fit coupon first. Mesh merged at 0.001 mm tolerance; outward STL normals verified. Mesh merged at 0.001 mm tolerance; outward STL normals verified.
Rail_clamp_upper_+1_+1 | Rail_clamp_upper_p1_p1.stl | 1 | 50.0 | 36.0 | 5.0 | 11.0 | 0 | 1 | Top plane Z715. Four M4 bolts on 38 x 20 mm pattern. Actual drone interface UNVERIFIED. Mesh merged at 0.001 mm tolerance; outward STL normals verified. Mesh merged at 0.001 mm tolerance; outward STL normals verified.
Rail_clamp_lower_+1_+1 | Rail_clamp_lower_p1_p1.stl | 1 | 50.0 | 36.0 | 28.0 | 40.6 | 0 | 1 | 20.8 mm square tube clearance. Use M4 through-bolts; no printed threads. Fit coupon first. Mesh merged at 0.001 mm tolerance; outward STL normals verified. Mesh merged at 0.001 mm tolerance; outward STL normals verified.

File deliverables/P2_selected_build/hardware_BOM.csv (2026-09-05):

Item | Quantity | Provisional size or interface | Notes
Hopper module joining bolts | 32 | M4 x 16 with washers and locknuts | 16 vertical seam and 16 horizontal seam bolts
Throat rail bolts | 16 | M4 x 14 with washers and locknuts | Check stacked wall and rail thickness
Hinge clevis mounting bolts | 16 | M4 x 20 with washers and locknuts | Verify engagement and no projecting petal snags
Keeper carrier mounting bolts | 16 | M4 x 20 with washers and locknuts | Four bolt holes on each half of each carrier
Suspension bracket bolts | 16 | M4 x 18 with wide washers and locknuts | Load path into thin hopper wall requires testing
Door splice bolts | 8 | M4 x 22 with washers and locknuts | Two bolts per splice plate
Rail clamp bolts | 16 | M4 x 45 starting length; washers and locknuts | Includes P2 3 mm lower plate; verify actual stack
Door-limit eye bolts | 8 | M4 with washers and locknuts | Four carrier anchors and four door anchors; select stem length from actual stack
Door-limit cords | 4 | 2 mm nominal adjustable cord | Provisional 100 N WLL target each; eye-centre lengths in limit_cords.json; verify knots and shock load
Hinge pins | 4 | 5 mm stainless steel x 48 mm | Add washers and positive end retention; not printed pins
Hinge thrust washers | 8 | 5 mm ID | Allow for actual washer thickness when fitting
Keeper spindles | 2 | 6 mm steel x 44 mm | Two M3 cross connections; machining and strength need review
Spindle cross bolts | 4 | M3 x 26 with locking nuts | Match shaft and adapter hole alignment
Keeper thrust washers | 2 | 6.6 mm ID x 24 mm OD x 1 mm | Payload axial force bears on carrier shelf
Transport arming pins | 2 | 3 mm x 28 mm with retention loop | Remove both before commanded release
Servos | 2 | Hitec D954SW at 7.4 V | Selected actuator; measure loaded release torque/current
Servo mounting screws | 8 | M3 bolts with washers and locknuts; fit length | 48 x 10 mm hole centres; horn-height spacers as required
Purchased servo horns | 2 | Genuine compatible Hitec 25T double-arm metal horn | Choose opposed holes at radius 8–20 mm for slotted adapter; check supplied horn
Horn adapter screws | 4 | M2.5 through-bolts with washers and locking nuts | One screw on each side of output; select length from actual horn stack
Suspension studs | 4 | M6 x 136 mm | Nominal P2 geometry; verify nut/washer engagement before cutting
Suspension nuts | 12 | M6 locking nuts plus wide washers | Verify clearance and secure engagement
Mount rails | 2 | Aluminium square tube 20 x 20 x 2 mm x 350 mm | M6 holes at +/-130 mm; four clamps match P2 lower plate
Retention cover | 1 | Light fabric or suitable net about 320 x 320 mm | Reinforce four stud cutouts and secure all edges; validate propwash
Cover straps | 4 | Nonprinted straps | Keep away from propellers

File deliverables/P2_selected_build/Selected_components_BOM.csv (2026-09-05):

System | Quantity | Selected component | Ordering/interface requirement | Total nominal mass kg | Mass basis / limitation | Primary source
Propulsion | 4 | Hobbywing X6 Plus G2 with MFP24x8 | 2 CW + 2 CCW; 30 mm tube | 2.992 | Published total, four units | https://www.hobbywing.com/en/products/x6-plus-g2
Flight battery | 1 | Tattu standard LiPo 12S 22Ah 30C | Factory custom SB175 tails + matching 12S balance harness | 4.650 | Published +/-0.100 kg before custom-tail change | https://www.grepow.com/uav-battery/tattu-12s-lipo-drone-battery.html
Controller | 1 | Holybro Pixhawk 6X + standard baseboard | Use current matched board/cables | 0.074 | Published module+board estimate; harness additional | https://docs.holybro.com/autopilot/pixhawk-6x/technical-specification
Power module | 1 | Holybro PM08 CAN tinned-wire SKU15029 | 200 A module; official power/CAN harness | 0.185 | Published with cable | https://holybro.com/products/dronecan-pm08-power-module-14s-200a
GPS | 1 | Holybro M10 GPS SKU12040 | Compatible 10-pin GPS1 cable | 0.032 | Published | https://holybro.com/products/m10-gps
Receiver | 1 | RadioMaster RP3 V2 ELRS 2.4 GHz | 5 V CRSF; 2 antennas | 0.0046 | Published including antennas | https://www.radiomasterrc.com/products/rp3-expresslrs-2-4ghz-nano-receiver
Transmitter | 1 | RadioMaster Boxer ELRS 2.4 GHz | Matching region/firmware; ground equipment |  | Not airborne | https://www.radiomasterrc.com/products/boxer-radio-controller-m2
Release servo | 2 | Hitec D954SW | 7.4 V; matching 25T horns | 0.132 | Published excluding horns | https://www.hiteccs.com/public/uploads/data_sheet/HRC_D954SW_Specsheetv2.2_102-1729877827.pdf
Servo BEC | 1 | Hobbywing UBEC 25A HV | Set 7.4 V; separate servo power bus | 0.074 | Published | https://www.hobbywing.com/en/uploads/file/20221108/12f5024346c4952abc96da8c0f2ffc32.pdf
Carbon arms | 4 | Roll-wrapped 30 OD / 27 ID carbon tube | Start 515 mm nominal; trim only after pod fit | 0.441 | 214 g/m source x 2.06 m | https://www.easycomposites.co.uk/30mm-roll-wrapped-carbon-fibre-tube-metric
Centre plates | 2 | Quasi-isotropic CFRP 3 mm sheet | 400 x 400 mm; supplied DXFs | 1.536 | Solid bounding-volume estimate at assumed 1.6 g/cm3; subtract holes
Arm clamps | 16 | Custom CNC 6061-T6 half clamps | 8 complete split clamps; supplied dimensions |  | CAD volume in mass report; not printable
Frame bolts | 32 | M5 x 60 class 8.8 starting length | Washers and locking nuts; verify stack |  | Included in frame hardware allowance
Landing frame | 1 | Custom 6061-T6 tubular stand | 20x2 struts/outriggers; 24x2 skids; saddle/gusset fit-up |  | Included in landing allowance
Main connector | 1 | Anderson SB175 mated pair | 2 x blue 941 +4 x 1382 contacts; 1/0 AWG tails |  | Included in electrical harness allowance | https://www.andersonpower.com/content/dam/ideal-anderson-power-dotcom/product-assets/default/data-sheets/DS-SB175.pdf
Main fuse | 1 | Littelfuse JLLN200.X | 200 A /125 V DC; matching covered LFT30 holder |  | Fault-current/thermal coordination required | https://www.littelfuse.com/assetdocs/jlln-datasheet?assetguid=3a7bc9bf-d932-4401-bdc7-b39f302195cf
Power harness | 1 | Qualified insulated star-distribution harness | >=200 A main path; short supplied ESC branches; branch/BEC protection |  | See wiring document; verify duty and thermal limits
Precharge fixture | 1 | Enclosed ground-only resistor/switch fixture | 10 ohm >=500 W; switch/wire/fuse >=63 VDC 10 A |  | Ground equipment; design/test required
Charger | 1 | SkyRC PC1260 SK-100138 | Standard 12S LiPo + correct balance board/charge adapter |  | Ground equipment | https://www.skyrc.com/download/PC1260_Instruction_Manual_EN_V1.0.pdf
Retention and mounts | 1 | Battery pad, two straps, end restraint, avionics foam/straps | Secure cover and electrical cable strain relief |  | Included in allowance

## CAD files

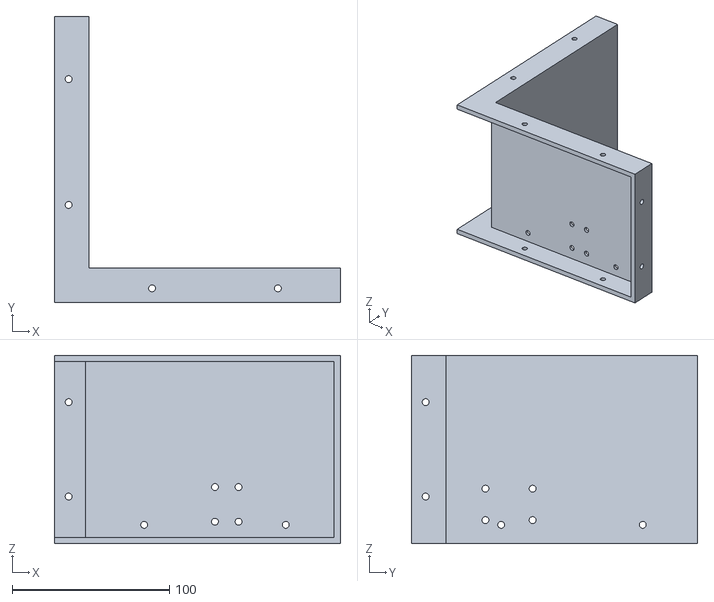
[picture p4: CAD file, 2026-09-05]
deliverables/P1_attachment_prototype/STL_mm/Hopper_lower_m1_m1.stl
181.8 x 181.8 x 119.8

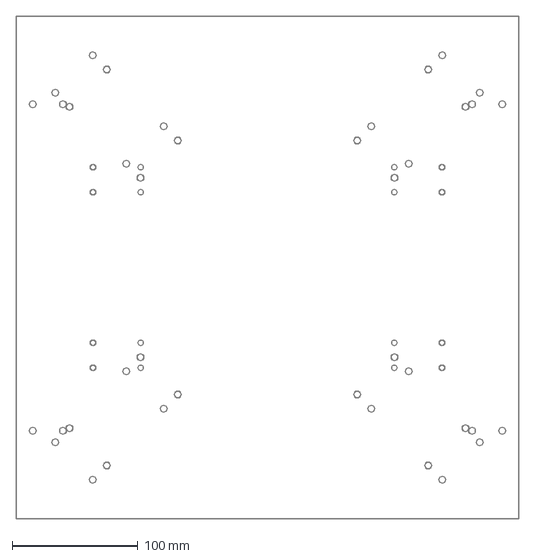
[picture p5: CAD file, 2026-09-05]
deliverables/P2_selected_build/Fabrication/Lower_frame_plate.dxf
400.0 x 400.0 mm

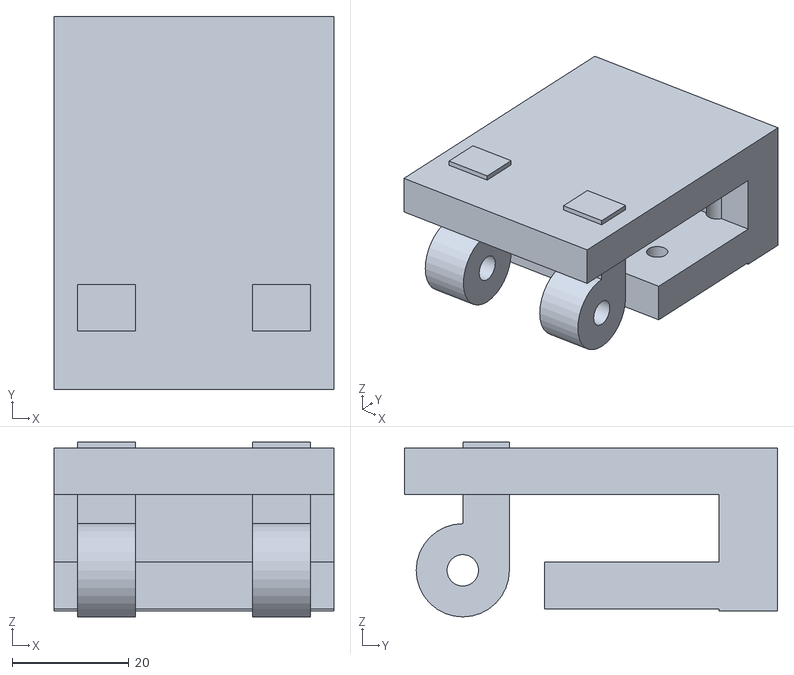
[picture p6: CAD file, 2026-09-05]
deliverables/P2_selected_build/STL_mm/Hinge_clevis_p1_m1.stl
48.0 x 64.0 x 30.0

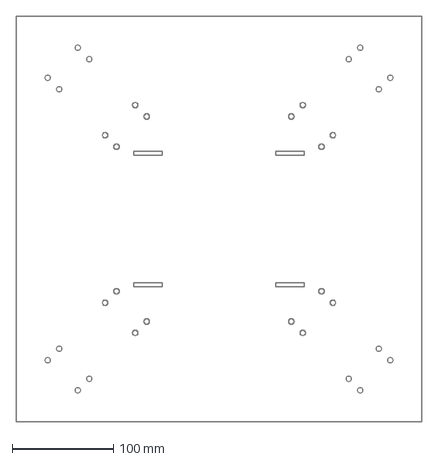
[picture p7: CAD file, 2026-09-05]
deliverables/P2_selected_build_view_copy/Fabrication/Upper_frame_plate.dxf
400.0 x 400.0 mm

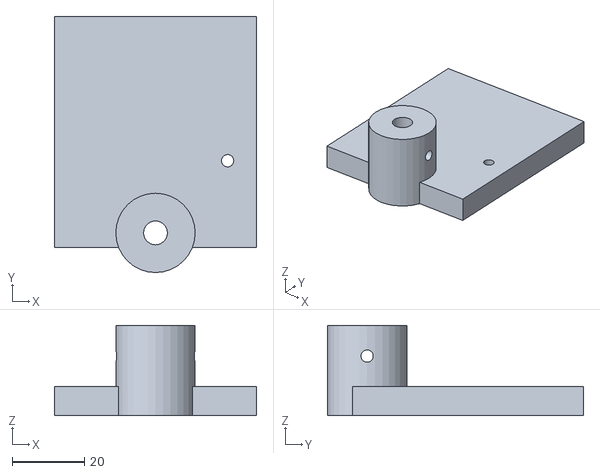
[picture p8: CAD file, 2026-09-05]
deliverables/P1_attachment_prototype/STL_mm/Keeper_dog_m1.stl
56.0 x 71.0 x 25.0

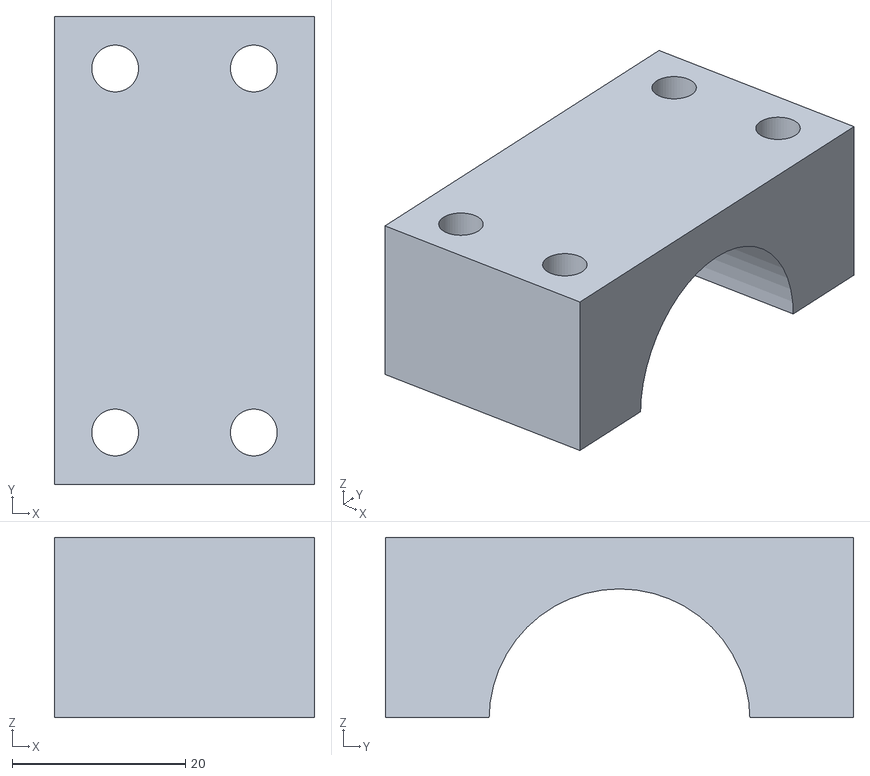
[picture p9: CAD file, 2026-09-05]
deliverables/P2_selected_build/Fabrication/MACHINED_6061_clamp_r130_+1_+1_half+1.stl
30.0 x 54.0 x 20.8

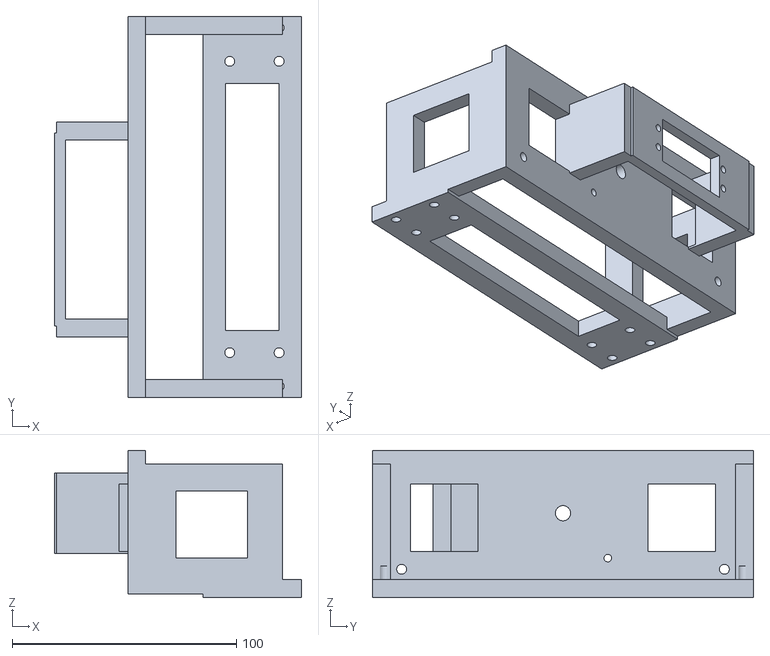
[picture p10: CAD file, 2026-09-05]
deliverables/P2_selected_build/STL_mm/Servo_keeper_carrier_p1.stl
110.2 x 170.0 x 65.6

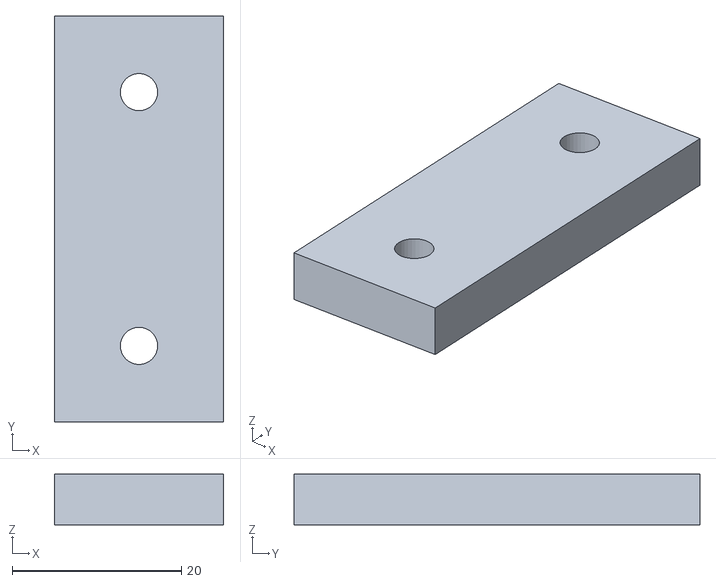
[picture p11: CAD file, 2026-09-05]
deliverables/P2_selected_build_view_copy/STL_mm/Door_splice_p1_125.stl
20.0 x 48.0 x 6.00

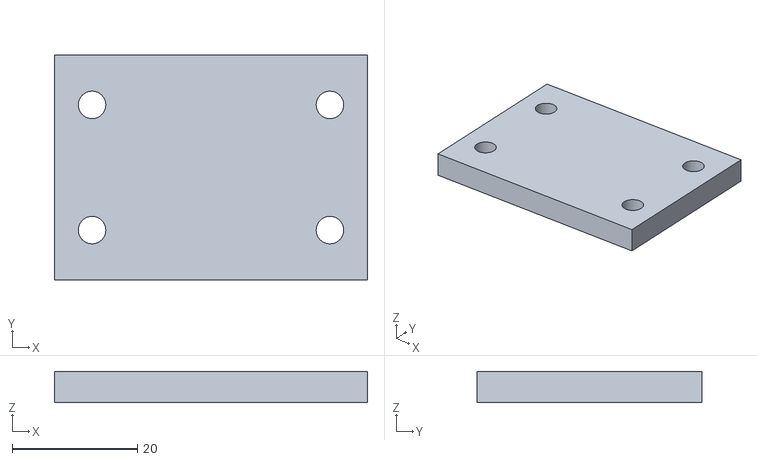
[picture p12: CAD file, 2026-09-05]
deliverables/P1_attachment_prototype/STL_mm/Rail_clamp_upper_m1_m1.stl
50.0 x 36.0 x 5.00

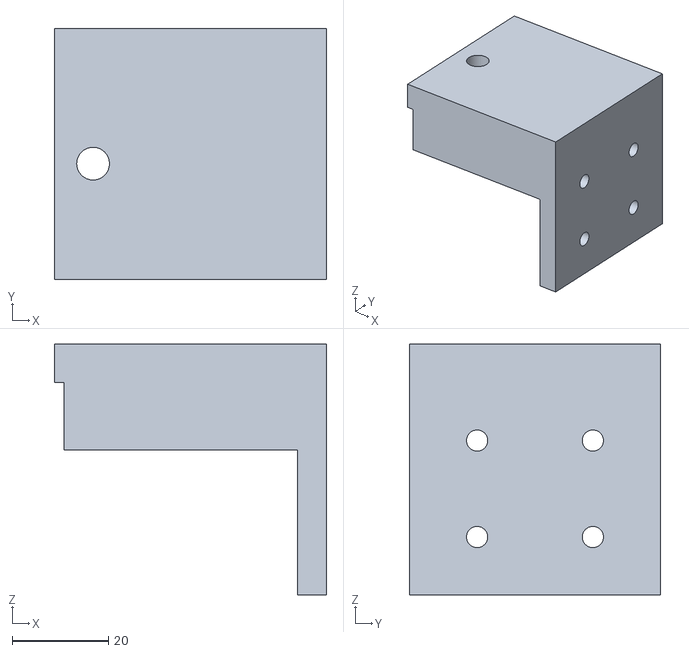
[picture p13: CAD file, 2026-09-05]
deliverables/P2_selected_build/STL_mm/Suspension_bracket_p1_p1.stl
56.4 x 52.0 x 52.0

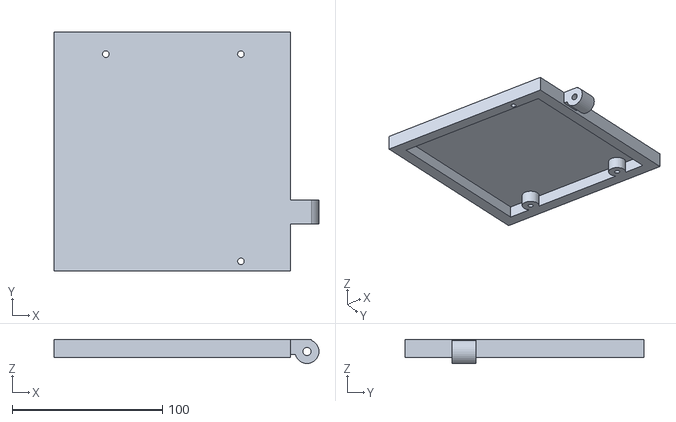
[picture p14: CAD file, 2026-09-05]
deliverables/P2_selected_build_view_copy/STL_mm/Door_tile_p1_m1.stl
176.5 x 159.3 x 16.0

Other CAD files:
deliverables/P2_selected_build_view_copy/STL_mm/Hopper_lower_m1_m1.stl
deliverables/P1_attachment_prototype/STL_mm/Hopper_lower_p1_m1.stl
deliverables/P2_selected_build/STL_mm/Hinge_clevis_m1_m1.stl
deliverables/Dronetara_Starter.blend
deliverables/P1_attachment_prototype/PetalDrop_1kg_Assembly.blend
deliverables/P1_attachment_prototype/STL_mm/Door_splice_m1_125.stl
deliverables/P1_attachment_prototype/STL_mm/Door_splice_m1_35.stl
deliverables/P1_attachment_prototype/STL_mm/Door_splice_p1_125.stl
deliverables/P1_attachment_prototype/STL_mm/Door_splice_p1_35.stl
deliverables/P1_attachment_prototype/STL_mm/Door_tile_m1_m1.stl
deliverables/P1_attachment_prototype/STL_mm/Door_tile_m1_p1.stl
deliverables/P1_attachment_prototype/STL_mm/Door_tile_p1_m1.stl
deliverables/P1_attachment_prototype/STL_mm/Door_tile_p1_p1.stl
deliverables/P1_attachment_prototype/STL_mm/Hinge_clevis_m1_m1.stl
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

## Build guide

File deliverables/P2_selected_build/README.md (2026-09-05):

# Dronetara P2 — selected aircraft + 1 kg petal-drop prototype

The design target is **at least 1 kg of flower petals alone**. The aircraft, battery, hopper and hardware are additional mass. This package chooses the aircraft and electronics from scratch; it does not require an existing drone.

P2 contains an editable Blender assembly, 46 individual printable attachment parts, a proposed carbon/aluminium airframe, plate machining files, component BOM, wiring plan and qualification worksheet. It is a **digital engineering prototype**. No parts have been printed, weighed, load-tested or flown, and no physical petal-release test has been performed. The 1 kg capacity remains conditional on actual petal volume and structural/release tests.

## Chosen build

- Custom Quad X, 1,300 mm diagonal motor spacing, four 30 mm carbon-tube arms and two 400 × 400 × 3 mm carbon-sheet centre plates. Machined aluminium split clamps carry arm loads; these are not printable parts.
- Four **Hobbywing X6 Plus G2** integrated propulsion units with genuine **MFP24×8** props, two CW and two CCW. The clearance model uses the published 620 mm prop span. The 30 mm tube interface is sourced; the detailed pod shape and tube insertion offset remain reference envelopes. Trim arms to obtain the specified motor centres using the actual units. [Manufacturer](https://www.hobbywing.com/en/products/x6-plus-g2)
- **Tattu standard LiPo 12S 22 Ah 30C**, not a LiHV or semi-solid substitute. Request the specified high-current power termination and a balance harness compatible with the charger; this is a supplier configuration, not a verified stocked SKU. [Battery family](https://www.grepow.com/uav-battery/tattu-12s-lipo-drone-battery.html)
- **Holybro Pixhawk 6X**, **PM08-CAN tinned-wire power module**, **M10 GPS**, and **RadioMaster RP3 V2 ELRS 2.4 GHz** receiver with an ELRS transmitter.
- Two **Hitec D954SW** release servos, genuine matching 25T horns, and **Hobbywing UBEC 25A HV set to 7.4 V**. Corrected carriers use the manufacturer's 48 × 10 mm mounting centres and shaft-relative offsets. The slotted adapters avoid inventing a printable servo spline. Horn fit still needs a bench check.

The conservative design ceiling is **21 kg all-up** for this prototype. It is a sizing assumption, not a certified maximum takeoff weight. Read `Mass_and_Performance.md` for the mass budget, hover estimate and operating limits.

## Files

| File/folder | Use |
|---|---|
| `PetalDrop_1kg_Assembly.blend` | Complete editable P2 drone and attachment; mm scene; named collections |
| `STL_mm/` | 46 separate printable attachment pieces; one of each filename |
| `parts_manifest.csv` / `.json` | Individual dimensions, print notes and solid PETG estimates |
| `Fabrication/` | Nonprinted plate DXFs, hole coordinates, machined clamp references and cut list |
| `Selected_components_BOM.csv` | Aircraft, electronics and ground-equipment selection |
| `hardware_BOM.csv` | Attachment screws, pins, washers, cords and rails |
| `Electrical_and_Setup.md` | Supply separation, signal connections and bench setup |
| `Mass_and_Performance.md` | Reproducible analytical sizing, assumptions clearly separated from measurements |
| `Qualification.csv` | Blank physical acceptance records; no fabricated pass results |
| `final_checks.json` | Independent exported-STL checks and sampled mechanism sweep |
| `Assembly_closed.png`, `Assembly_open.png`, `Mechanism_open.png` | Closed, discharge and underside views |

The original starter and P1 package remain preserved in the parent output folder. Use P2 files together; do not mix the earlier servo carriers or horn adapters into this build. Blender geometry is editable mesh geometry, not a parametric STEP assembly. Procedural source scripts are included in `Source/` for review and adaptation.

## Capacity and release mechanism

The hopper has a 320 × 320 mm interior, a fill datum at Z570 mm, and approximately **22.12 litres** below that line before hardware displacement. The geometric requirement for 1 kg is a loose bulk density of at least **45.21 kg/m³**; actual usable volume is slightly less. No universal petal density is assumed. Weigh and loosely fill representative dry and damp batches. If a full 1 kg batch does not fit below the line with its cover, the hopper must be enlarged and rechecked.

Two ribbed doors form the bottom. Each of two keeper dogs supports the inner edges of both doors. The load travels through the dog, thrust washer and carrier shelf into the hopper; the servo rotates a separate steel spindle. Hinges carry part of the door load. The doors open by gravity after the keepers rotate 90 degrees. Four adjustable cords limit opening to a nominal 95 degrees. The broad 292 × 292 mm throat helps release, but does not prove that wet or tangled petals cannot bridge.

**Reset is manual.** Raise and support the empty doors, return both keepers, then insert both 3 mm transport pins. Remove both pins before commanding release. The P1 unengineered spring illustrations have been removed. With transport pins removed there is no demonstrated power-loss retention mechanism; friction and servo gearing are not a qualified mechanical lock.

| Timeline frame | Operation |
|---|---|
| 1 | Closed, transport pins installed |
| 20 | Pins removed |
| 20–50 | Keepers rotate clear |
| 50–90 | Gravity door opening to cord limit |
| 90–105 | Open discharge state |
| 105–125 | Manual empty-door lifting, illustrated with keyframes |
| 125–155 | Keeper return under supported doors |
| 180 | Pins reinstalled |

Animation illustrates the sequence; it is not a physics simulation or flight-control program.

## Printing and mechanical assembly

Import STLs as **millimetres at 100% scale**. Each exported part fits a 220 mm cube. Export orientation places its bounding box on the bed; choose final support and layer orientation in the slicer. The starting geometry has 2.4 mm hopper walls/door skins, 4 mm hopper flanges, 0.4 mm module seams, 5.4 mm hinge bores for 5 mm pins, and typical 4.4 mm M4 holes. These are nominal design dimensions, not measured printer tolerances.

Use a calibrated material profile, initially a 0.4 mm nozzle and 0.2 mm layers. Slice and weigh a hinge, carrier and suspension bracket first. PETG density of 1.27 g/cm³ is only the planning assumption used in the manifest. Wall count, infill and layer direction need material/process testing; no infill percentage guarantees payload strength.

1. Bolt the eight corner modules together using wide washers and locknuts. Keep seams even and seal externally. Install the eight throat rails, four hinge clevises and four suspension brackets.
2. Join each pair of door tiles using two underside splice plates. Fit four steel hinge pins, thrust washers and positive end retention. Confirm free travel by hand.
3. Install the two corrected D954SW carriers, thrust washers, steel spindles and keeper dogs. The ear support is Z290.8 mm; output height is based on the drawing. Actual grommets and horn thickness may require spacers. Check the 6 mm spindle axis is concentric with the servo output and does not force an axial load into the servo.
4. Bolt each slotted adapter to a genuine compatible 25T double-arm horn with two opposed M2.5 through-bolts and washers. The slots accept hole radii of 8–20 mm. This is an adjustable interface, not a claim that every supplied horn has that pattern. Select a horn with two suitable holes, or drill an appropriate metal horn using its supplier's limits. Do not substitute a printed spline or rely on adhesive. Check screw access and the full rotation before fastening the spindle cross-bolts.
5. Fit eight M4 eye bolts and four nonprinted cords. Set nominal eye-centre lengths to **113.946 mm at the 95° open position**, then adjust for actual eye geometry, knots and stretch. The provisional selection target is at least 100 N working load per cord; anchor strength and opening shock require testing. Keep slack cords out of the latch path.
6. Install four M6 studs and two 20 × 20 × 2 mm aluminium rails. Four split rail clamps attach to the matching M4 hole sets in the lower carbon plate. Top clamp faces meet Z715. Use the P2 plate DXF; this interface is now designed into the chosen frame.
7. Assemble the carbon plates, eight machined split arm-clamp assemblies and carbon tubes. Follow `Fabrication/Cut_list.md`. Carbon clamping torque is not established; qualify slip resistance without crushing/delaminating the tube. Do not treat the reference pod envelope as a drilling template.
8. Fit the fabricated tubular landing stand. The outriggers run below the carbon arms, leaving the door sweep clear. Weld/gusset design, heat-affected material strength and landing-load qualification are still fabrication engineering work.
9. Secure the battery with a resilient pad, two independent webbing straps and end restraint. Retain the controller on vibration-isolating foam with straps; provide connector access. Secure all electronics, the fabric petal cover and cable slack.

Lengths in the fastener BOM are starting selections. Verify stack thickness, washer access, full locknut engagement and no projecting threads in the petal path. All primary aircraft structure is purchased carbon or fabricated metal. Do not print props, motor clamps or structural plate substitutes.

## What the digital checks establish

`final_checks.json` validates the actual binary STLs, separately from Blender's in-memory meshes. It also samples keeper motion from 0–90° and doors from 0–95° in 1° increments against fixed printable parts and landing references. Zero reported surface intersections is not continuous collision proof: contact/deformation, hardware interiors, wires, flexible cords, petals and aerodynamics are outside that check. Exact seating contacts, supplied horn details and fastening remain physical checks.

The frame and component envelopes are for a reviewable prototype build. The plate mounting patterns and printable mechanism are modeled, but motor-pod internals, welded landing joints, battery termination and horn stack are not production-qualified interfaces. No FEA, material coupon test, fatigue assessment, thrust-stand test or reliability demonstration is represented as complete.

Use `Qualification.csv` to record actual results. Start with the stationary mechanism and propellers removed. Confirm fit, weigh the assembly, retain a real 1 kg batch, measure loaded release torque/current, test at least 20 screening cycles across representative petals, and record residual mass. Establish structural proof loads from intended manoeuvre/landing loads and real material data. Then qualify the complete electrical installation and propulsion in a restrained test fixture before progressive flight tests at an appropriate clear test site. A 20-cycle screen is not a reliability certification.

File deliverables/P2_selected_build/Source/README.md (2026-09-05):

# Procedural sources

The root P2 assembly and exports are the deliverables. This folder contains editable regeneration sources and the preserved P1 mechanism seed used by P2. `P1_base` is reconstruction input only; do not print or build from its older specifications.

Work in a COPY of the package: regeneration overwrites output files. Run in this order using Blender 5.2 (factory startup avoids user add-ons in background):

1. Blender `--background --factory-startup --python Source/build_p2.py`
2. Python 3 `Source/write_p2_docs.py`
3. Blender `--background --factory-startup --python Source/finish_p2.py`
4. Blender `--background --factory-startup --python Source/finalize_p2.py`
5. Blender `--background --factory-startup --python Source/check_p2.py`

Geometry builders use millimetres. Manufacturer reference envelopes are explicitly labeled. Edit the geometry and docs together. Regenerated files need a fresh inspection and verification; do not reuse old checksums or claim a modified part is qualified because this version passed topology checks. Scripts depend on Blender's bundled bpy/bmesh; they are not ordinary standalone Python CAD programs.

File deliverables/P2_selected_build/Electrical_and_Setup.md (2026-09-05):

# P2 electrical architecture and bench setup

This is a connection plan, not a tested harness or a flight-ready parameter file. Use the official pinout for the delivered board revision and cable labels. Never infer pin order from connector shape or wire colour alone.

## Power

```text
12S standard LiPo (50.4 V full)
  -> factory high-current tails / SB175 main connector
  -> 125 V DC Class T main fuse in insulated holder
  -> PM08-CAN tinned-wire power module
  -> insulated star distribution
       -> four X6 Plus G2 integrated ESC/motor units
       -> UBEC 25A HV input -> 7.4 V dedicated servo power bus
PM08 regulated 5.3 V output -> Pixhawk POWER1
PM08 second regulated output -> POWER2 using official compatible harness
PM08 CAN -> Pixhawk CAN (correct termination and power/telemetry harness)
Pixhawk 5 V accessory output -> M10 GPS / RP3 receiver as appropriate
Pixhawk AUX1 signal + ground -> both servo signal inputs
```

The two PM08 outputs share one flight battery; they are not independent battery redundancy. Keep servo high-current returns on the BEC harness and join signal reference ground. **Do not connect the 7.4 V servo supply to the Pixhawk 5 V power or accessory input.** Do not feed BEC voltage back through a three-wire Y-lead into the autopilot: use signal/ground breakout and separate power injection.

The [PM08-CAN](https://holybro.com/products/dronecan-pm08-power-module-14s-200a) provides a published 200 A continuous rating and 5.3 V regulator outputs. Choose the tinned-wire variant to avoid a stock connector becoming the limiting component. Its short supplied 8 AWG leads are part of the manufacturer's rated module; retain them and use qualified crimped/busbar transitions, insulation and strain relief.

The selected [UBEC 25A HV](https://www.hobbywing.com/en/uploads/file/20221108/12f5024346c4952abc96da8c0f2ffc32.pdf) supports this input voltage and the two-servos' combined published stall demand of 10.4 A at 7.4 V. Use separate appropriately rated servo supply branches and short extensions at least as substantial as the servo's supplied 20 AWG cable. Measure actual connector and wire temperature under the release duty cycle. Supply capacity does not make sustained servo stall acceptable.

For the main connector select Anderson **SB175 blue 941 housing with 1382 1/0 AWG contacts**, matching both sides and professionally crimped short 1/0 AWG tails. Its current capability depends on contacts, cable, ambient temperature and tooling. It is not inherently an anti-spark connector. [Manufacturer datasheet](https://www.andersonpower.com/content/dam/ideal-anderson-power-dotcom/product-assets/default/data-sheets/DS-SB175.pdf)

The battery manufacturer must confirm that termination and its mass, insulation, strain relief and current capability. It is a custom procurement requirement; do not modify a live pouch pack or assume a smaller supplied plug is equivalent. Use an enclosed, professionally assembled precharge arrangement before main connection. A ground-only precharge fixture can use a 10-ohm, at least 500 W resistor bank and a momentary switch/fuse/wiring rated at least 63 V DC and 10 A. At 50.4 V its initial current/power are 5.04 A/254 W. Measure bus voltage; connect the main plug only when the voltage difference is below 2.5 V. If this cannot be achieved within the fixture's qualified duty, stop and resolve the load/circuit. Disconnect the ground fixture after main engagement. This proposed fixture has not been built or tested.

Select **Littelfuse JLLN200.X**, a 200 A Class T fuse with a 125 V DC rating and 20 kA DC interrupt rating, in a matched covered LFT30-series holder sized for 200 A. Confirm that the battery/harness prospective fault current is below that rating and coordinate the fuse curve with the actual conductors and holder temperature. This fuse is not an instantaneous 200 A motor-current limiter. The selected high interrupt rating avoids relying on a low-interrupt automotive fuse for the large LiPo source. [JLLN datasheet](https://www.littelfuse.com/assetdocs/jlln-datasheet?assetguid=3a7bc9bf-d932-4401-bdc7-b39f302195cf)

## Signals and control

| Function | Connection / configuration |
|---|---|
| Four motors | Pixhawk MAIN1–4 PWM signal and ground to corresponding integrated ESCs |
| Petal release | AUX1 / output 9 signal and ground to a powered two-servo breakout; mechanically index both keepers to move clear together |
| Receiver | RP3 TX to TELEM2 RX; RP3 RX to TELEM2 TX; regulated 5 V and ground |
| GPS/compass | Holybro M10 compatible GPS1 cable; verify connector version before power |
| Power telemetry | PM08 DroneCAN to a CAN port; configure sensor type and verify voltage/current against instruments |
| Ground setup | USB with propellers removed; install current stable ArduCopter supported by Pixhawk 6X |

For this model, front is **negative Y**, right is positive X. Standard ArduCopter Quad X mapping is MAIN1 front-right, MAIN2 rear-left, MAIN3 front-left, MAIN4 rear-right. Verify rotation against the current [official motor diagram](https://ardupilot.org/copter/docs/connect-escs-and-motors.html) and the installed CW/CCW props. Perform the software motor test with props removed; test order letters are not the same as output channel numbers.

The selected integrated ESC uses fixed PWM endpoints 1050–1950 μs; do not perform an unsupported endpoint calibration. Start with ordinary PWM, following its manual's startup/ramp recommendations. Verify that the controller's output logic level is accepted at the end of the actual harness; the Blender assembly does not establish electrical signal margins.

The [ArduPilot servo-gripper workflow](https://ardupilot.org/copter/docs/common-gripper-servo.html) uses `GRIP_ENABLE=1`, `GRIP_TYPE=1`, and `SERVO9_FUNCTION=28` for AUX1. Assign a deliberate RC switch, for example `RC8_OPTION=19`. Calibrate `GRIP_GRAB` and `GRIP_RELEASE` on the unloaded bench. Do not copy generic 1000/2000 μs values: the servos must achieve the required 90° without loading their stops. Use a servo-appropriate 50 Hz output group. Disable automatic closing because door raising is manual. Configure and test retention on RC loss rather than an automatic payload-release failsafe.

For CRSF on TELEM2 use `SERIAL2_PROTOCOL=23` when that connector maps to SERIAL2 on the selected board. Both TX and RX are required. Bind matching ELRS firmware/region and confirm channel ranges, link-loss behaviour and telemetry. [ArduPilot RC documentation](https://ardupilot.org/plane/docs/common-rc-systems.html)

Do not fly with these notes as a substitute for sensor calibration, motor order/rotation checks, controller tuning, verified failsafes, battery monitoring and a qualified load/current envelope. `MOT_BAT_CURR_MAX` is a delayed software control, not an instantaneous protective fuse. See [current limiting](https://ardupilot.org/copter/docs/current-limiting-and-voltage-scaling.html).

## Charging

Select **SkyRC PC1260 SK-100138** in standard 12S LiPo balance mode, using its correct 12S balance board and a professionally wired charge adapter. A charge-only XT90 adapter may be used at the charger's limited current; it must never be inserted into the flight power path. Start at 10 A, within the charger's published 12 A per-channel limit and below the battery's 1C rate. Verify cell count, lead polarity and all balance taps before connection. Never use a LiHV profile for the selected standard LiPo. [PC1260 manual](https://www.skyrc.com/download/PC1260_Instruction_Manual_EN_V1.0.pdf)

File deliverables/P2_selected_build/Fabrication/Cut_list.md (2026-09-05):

# P2 nonprinted fabrication — mm

These are prototype manufacturing inputs, not released/certified structural drawings. Do not move these meshes into the printable parts folder.

- Two 400 × 400 × 3 mm quasi-isotropic CFRP plates. Lower bottom/top Z715/718; upper bottom/top Z760/763. Machine the corresponding DXFs, centered on X/Y zero. Hole JSON files give an independent circular-hole coordinate list. The upper plate also has four 28 ×4 mm rectangular strap slots centred at (±70, ±65), included in its DXF. Verify a 400 mm outside dimension after import; DXF is mm. Seal cut carbon edges and isolate galvanic contact with aluminium without silently changing the clamp stack.
- Four 30 OD /27 ID roll-wrapped carbon arms, nominal cut length 515 mm. Inner radius 110 mm, nominal outer radius 625 mm. Motor centres are radius 650 mm at ±45°/±135°: X/Y = ±459.619 mm. The last 25 mm centre offset is a packaging assumption, not a verified X6 pod dimension. Dry-fit actual pods, respect their specified full insertion and adjust tube length to motor centres before cutting. Follow manufacturer's clamp fastening procedure.
- Eight complete machined 6061-T6 split clamps: sixteen halves. Full envelope 30 mm radial ×54 mm tangential ×42 mm high, axis Z739; radial bore Ø30.10 mm; half-gap 0.40 mm before tightening. Each half is 20.80 mm high. Four Ø5.4 mm holes have radial/tangential centres ±8/±21 mm (16 ×42 pattern). Clamp centres at radius 130 and 210 mm on every arm. Meshes are local-axis machining references; dimensions here are authoritative. Tolerances must be set by the fabricator for the purchased carbon tube, surface finish and grip trial. Inspect tube crush/slip; no torque has been qualified.
- Thirty-two M5 through-bolts, nominal 60 mm, with washers and locknuts. Verify stack and thread protrusion. The same four bolts join top plate, upper clamp, lower clamp and bottom plate at each station.
- Lower plate has sixteen Ø4.4 mm hopper-mount holes, arranged on four 38 ×20 mm patterns centered at (±120, ±70). These match the upper halves of the printed rail clamps.
- Landing saddle pairs: Ø5.4 mm at X = ±175 ±12, Y = ±130. Four 40 ×24 ×6 mm aluminium saddle plates, top Z715. Two holes in each on a 24 mm line. Eight M5 bolts with washers/locknuts; choose length from physical stack.
- Four 20 OD ×2 mm wall aluminium outriggers: from (±175, ±130,680) to (±260, ±220,680), approximately 123.794 mm centreline. Four same-section main legs: (±260,±220,680) to (±290,±245,40), approximately 641.190 mm centreline. Four vertical saddle drops: 29 mm nominal centreline. Two 24 OD ×2 mm wall skids: X±290, Y−300 to+300, Z30; 600 mm each. Coordinate signs pair consistently within each corner. Miter/cope and end fit change raw cut lengths. Landing pads are nonprinted elastomer.
- The landing joints need actual saddle/gusset/weld design and allowance for 6061 weld heat effects; reference intersecting tubes do not constitute a joint detail. A fabricator must resolve joints and qualify landing loads before flight. This is an explicit remaining engineering interface.
- Hopper rails: two 20 ×20 ×2 mm aluminium square tubes, 350 mm long, with Ø6.6 mm suspension holes at longitudinal ±130 mm. Four M6 studs, nominal 136 mm, adjust only for actual washer/nut engagement.

Structural adhesives, printed substitutes, unsupported welded joints and guessed carbon-clamp torque are not specified as load-rated solutions. The Blender model establishes packaging and assembly interfaces; real material data and proof tests establish capability.

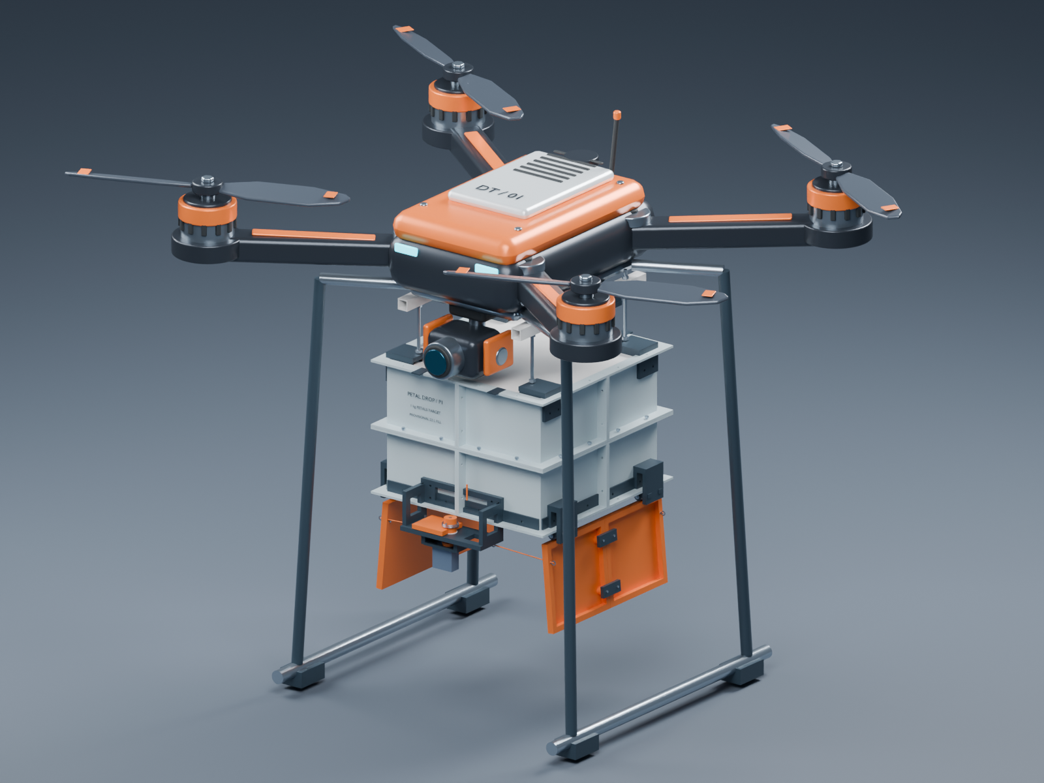
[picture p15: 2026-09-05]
deliverables/P1_attachment_prototype/Assembly_open.png

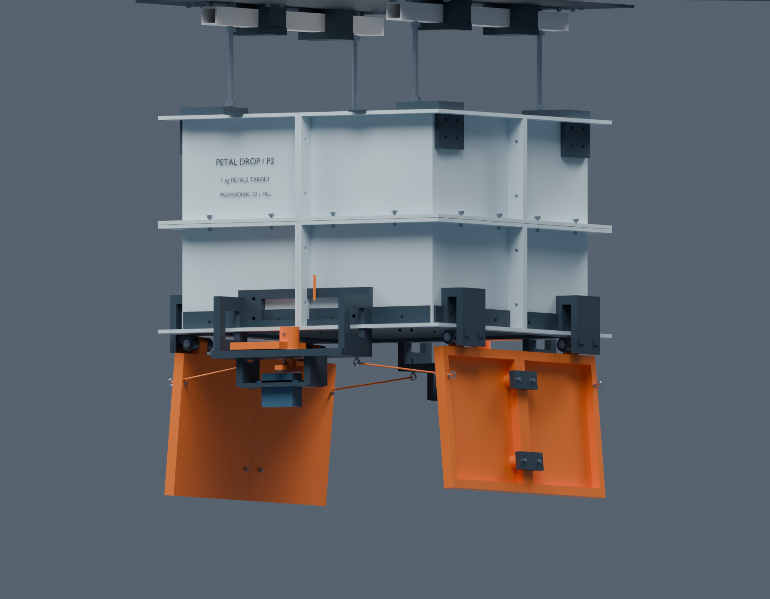
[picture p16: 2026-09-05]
deliverables/P2_selected_build/Mechanism_open.png

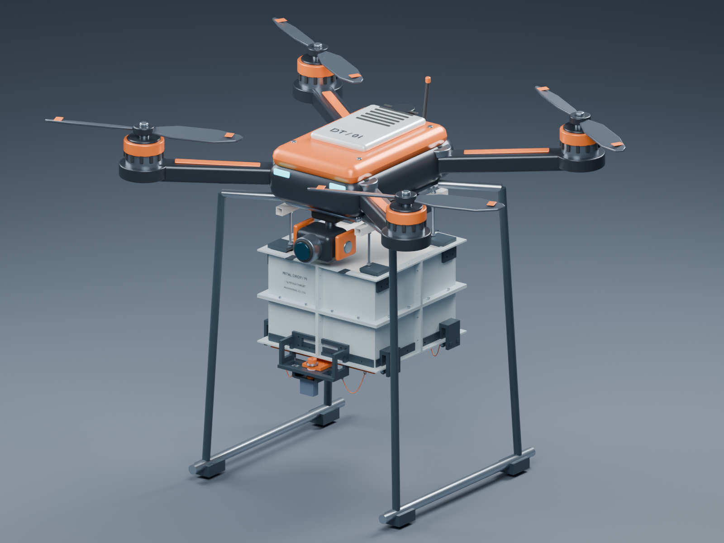
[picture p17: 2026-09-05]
deliverables/P1_attachment_prototype/Assembly_closed.png

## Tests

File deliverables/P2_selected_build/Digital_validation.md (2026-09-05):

# P2 digital validation

- 46 delivered printable STL binaries checked independently: zero boundary/nonmanifold edges, zero degenerate triangles, positive signed volume, valid binary length.
- Each printable part is one connected solid and fits a 220 mm cube. Coordinates are millimetres.
- 91 keeper states and 96 door states, sampled at 1°: no surface intersections in the stated moving-versus-fixed-print/landing scope.
- Nominal minimum sampled printed door-to-ground gap: 176.312 mm. This is upright model geometry, not flight clearance.
- Upper/lower plate DXFs checked against circular-hole lists: 32/56 holes. Upper plate has four rectangular battery strap slots. Both outer outlines are 400 ×400 mm.
- Closed, open and underside renders visually inspected; final P2 file opened in the user's Blender application. The prior unsaved P1 UI scene was copied to the work folder before replacement.
- No physical load, release, material, electrical, thrust or flight test was performed. Read the qualification worksheet and interface limitations in the guide.

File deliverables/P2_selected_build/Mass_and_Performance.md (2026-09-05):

# P2 mass and performance sizing

The planning total is **20.28 kg**, including **1.000 kg of petals** and 0.500 kg of contingency. The design ceiling is 21 kg, leaving another 0.72 kg before that ceiling. This is not weighed mass or an approved takeoff limit. See `Mass_budget.csv` and `sizing.json` for reproducible inputs.

| Item | kg | Basis |
|---|---:|---|
| Printed attachment | 3.751 | CAD solid volume; assumed PETG 1.27 g/cm3 |
| Attachment rails/fasteners/cords/cover/horns | 1.000 | Planning allowance, excludes servos |
| Two release servos | 0.132 | Published, excluding horns |
| Four propulsion units | 2.992 | Published with props and cables |
| Battery | 4.650 | Published nominal; custom-tail difference in harness allowance |
| Carbon centre plates | 1.525 | CAD volume; assumed CFRP 1.6 g/cm3 |
| Machined arm clamps | 0.922 | CAD volume; assumed aluminium 2.7 g/cm3 |
| Carbon arms | 0.441 | Supplier linear mass x nominal tube length |
| Tubular landing members | 1.414 | CAD volume; assumed aluminium 2.7 g/cm3 |
| Landing saddles/gussets/pads | 0.200 | Allowance beyond tubular members |
| Aircraft fasteners | 0.550 | Allowance including washers, nuts and mounting bolts |
| FC/PM/GPS/RX/BEC | 0.370 | Published component masses, approximate |
| Power distribution, fuse, connector, added wiring | 0.650 | Allowance; weigh custom harness |
| Straps/foam/avionics supports | 0.180 | Allowance |
| Petals | 1.000 | Required payload alone |
| Unallocated mass contingency | 0.500 | Planning reserve |

Thin printed walls remain largely solid regardless of infill. Do not subtract a guessed infill percentage from the whole attachment. Actual fasteners, battery termination, weld gussets, supports and wire routing may exceed their allowances. Weigh the complete aircraft after assembly; if it exceeds 21 kg, reduce mass or resize/requalify the propulsion.

## Lift and current

At 21 kg, hover requires 5.25 kg thrust per motor. Interpolation between the manufacturer's 46 V laboratory points (4,712 g at 12.4 A and 5,256 g at 14.7 A) gives approximately **58.7 A total / 2.70 kW**. This is a static sea-level estimate at the cited test conditions, not a flight measurement. The manufacturer's recommended 4–6 kg-per-axis range supports choosing this motor family. [Hobbywing X6 Plus G2](https://www.hobbywing.com/en/products/x6-plus-g2)

The published maximum 12.526 kg per unit would total 50.104 kg and a 2.39:1 ratio at 21 kg, but that maximum is outside the proposed routine electrical envelope and cannot be treated as continuous thrust. The integrated ESC's 25 A continuous rating limits four-unit continuous current to 100 A before accessory allowance; individual motor currents must also remain within their ratings. PM08's 200 A rating is not the motor limit.

For initial qualification, target at most **160 A bus for a maximum two-second transient**, below 100 A total propulsion current continuously, and verify each ESC separately. A preliminary command ceiling near the 78% laboratory point corresponds to 156.8 A and 39.144 kg total static thrust at 46 V, or 1.86:1 at 21 kg. Percent bench throttle is not guaranteed to map exactly to an autopilot parameter. Establish the actual PWM ceiling with current/thrust measurements at a full 50.4 V battery before flight. Servo/accessory current also belongs in the bus total.

A hypothetical 20% thrust derating reduces that transient figure to 31.315 kg, only 1.49:1 at 21 kg. To retain a 1.8:1 transient ratio in that scenario, mass would need to be at most 17.40 kg. Therefore this selection does **not** establish hot/high-altitude performance; qualify the intended environment or revise mass/propulsion. Software current limiting reacts too slowly to substitute for electrical sizing.

## Endurance and geometry

The standard 12S 22 Ah pack is nominally 976.8 Wh. Reserving 25% energy and adding 15% to the bench hover power plus 20 W for electronics gives approximately **14.1 minutes of analytical hover** at the 21 kg ceiling. Wind, manoeuvres, voltage sag, temperature, battery ageing and reserve policy change this. It is not a promised flight duration. [Battery specification](https://www.grepow.com/uav-battery/tattu-12s-lipo-drone-battery.html)

Adjacent motor centres are 919.24 mm apart. A nominal 620 mm swept diameter leaves 299.24 mm between adjacent rotor disks in plan. The detailed pod outline is approximate; confirm actual insertion and final rotor centres. Battery and GPS envelopes lie inside the central clear region. The mechanism's sampled minimum door-ground gap is recorded independently in `final_checks.json`; do not confuse it with clearance under pitch/roll or uneven ground.

The centered battery and hopper support a roughly centered plan CG, but hardware distribution and departing petals change it. Measure full/empty CG and recheck stability; no inertia model or autopilot tuning was completed.

## Release actuator and structure

The selected D954SW at 7.4 V has published 29 kgf·cm stall torque (2.844 N·m), 5.8 kgf·cm peak-efficiency torque (0.569 N·m), and 5.2 A stall current. Neither torque number is a continuous application rating. [Hitec drawing/data](https://www.hiteccs.com/public/uploads/data_sheet/HRC_D954SW_Specsheetv2.2_102-1729877827.pdf)

An intentionally conservative friction estimate of 0.4 × (1.7 kg ×9.81) ×0.060 m is 0.400 N·m if one keeper briefly carries that whole load. Real hinge load sharing may lower it; petal snagging may raise it. A threefold design target would require 1.20 N·m of verified short-duration output at the actual voltage/duty, not merely a larger stall number. This has not been demonstrated. Measure breakaway torque and actual loaded release current/temperature; change the actuator or bearing/contact design if margin is insufficient.

For a provisional 3g sizing case, a 21 kg aircraft corresponds to 618 N overall. An attachment around 6 kg corresponds to 177 N, nominally 44 N per suspension point under ideal sharing. Unequal load distribution, landing shocks, creep and layer adhesion invalidate treating those as certified loads. The frame/printed mounts still require engineering proof loads based on actual material properties and intended use. CAD topology and absence of sampled collision do not establish strength.
